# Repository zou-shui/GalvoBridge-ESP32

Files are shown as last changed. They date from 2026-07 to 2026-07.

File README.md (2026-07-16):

# GalvoBridge-ESP32：振镜双电源与数模转换一体化接口板

立创开源平台链接：[振镜双电源与数模转换一体化接口板 - 立创开源硬件平台](https://oshwhub.com/zoushui/project_hrrvwklm)

效果演示：[【开源】振镜驱动效果演示](https://www.bilibili.com/video/BV1rFKG6pEkv/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)

## 项目简介

**GalvoBridge-ESP32** 是一款专为模拟激光振镜系统设计的**一体化信号与电源适配接口板**。它集成了24V转±15V的**双电源转换模块** 与 **数字信号转模拟差分信号调理电路**，并集成了激光笔电源接口。

该项目旨在解决数字系统与模拟振镜系统之间的电压与信号鸿沟，实现一根 USB 线、一个24V电源即可轻松玩转振镜。

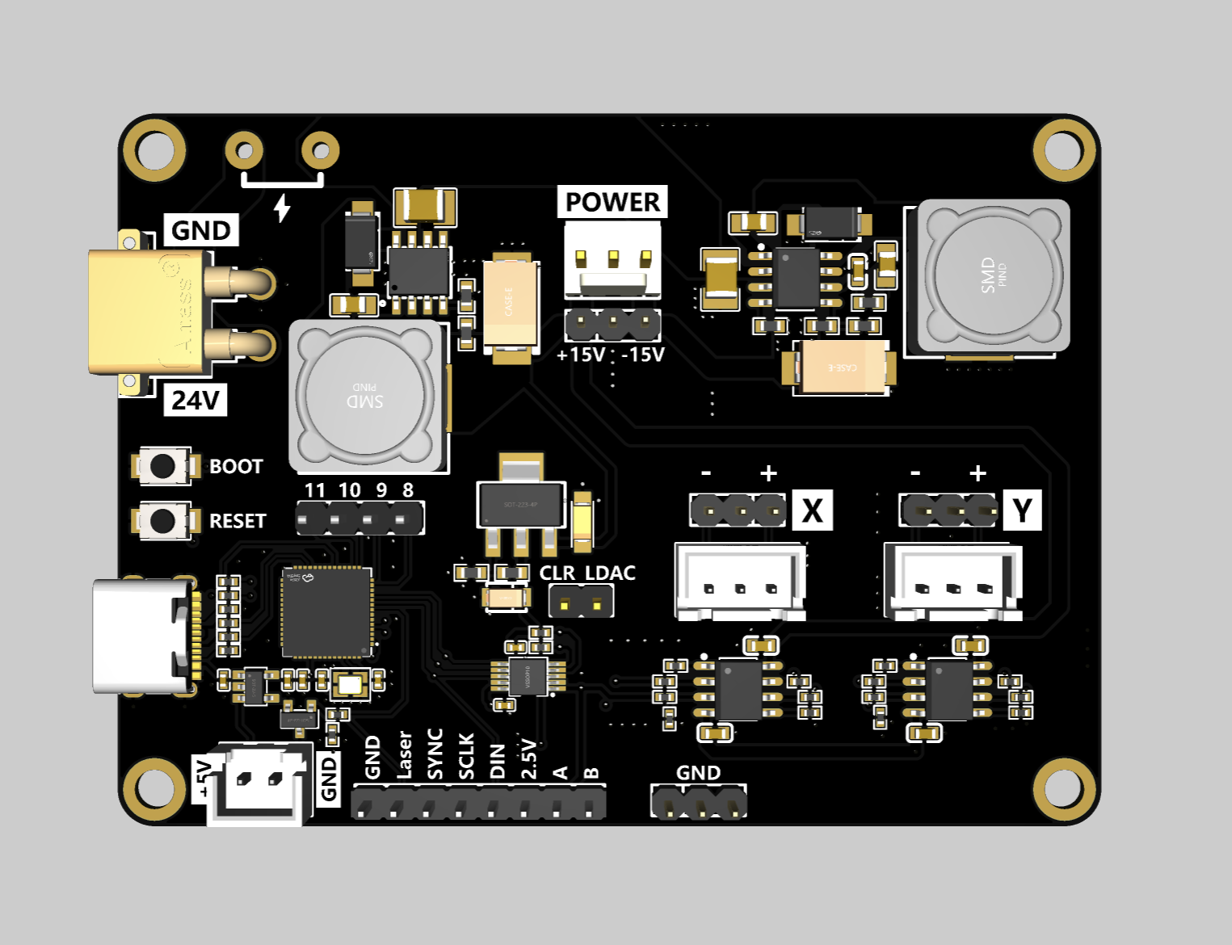
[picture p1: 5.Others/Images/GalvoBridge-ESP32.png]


## 为什么会有这个项目？

在进行激光打标、激光投影相关的 DIY 开发时，市售的振镜电机通常会成套附带一块原厂伺服驱动板（见下图）：

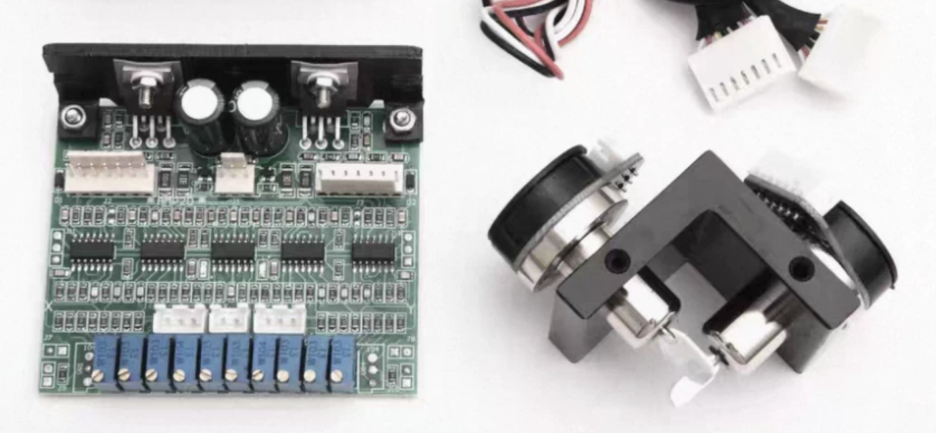
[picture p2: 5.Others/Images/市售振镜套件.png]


然而，在实际使用中，原厂驱动板存在两个“高门槛”：

1. **供电苛刻：** 振镜驱动板通常需要特殊的**±15V双电源**供电。在大多数整机系统中，标准电源都是单24V，额外配置一个体积庞大的双电源开关电源既增加成本又占地方。

2. **信号不匹配：** 振镜驱动板只接收**±5V的模拟差分信号**来控制振镜。单片机或DAC无法直接提供匹配的信号。

本项目解决了上述痛点。

## 实现原理

* **高负载双电源方案**：采用两颗高效率 DCDC 电源芯片，将整机常用的单路+24V电源分别转换为高电流能力的+15V和-15V双电源，直接为振镜伺服系统供电。

* **数模转换与信号调理**：核心主控采用 **ESP32-S3**，通过 USB 串口接收上位机数字指令并进行解析。控制高性能双通道 DAC 芯片输出高精度模拟信号，再经过运算放大器进行**电平平移（偏置）、幅度放大以及差分化处理**，最终输出±5V幅值的模拟差分信号。

## 详细参数

| 项目 | 参数 |
| --- | --- |
| 电源输入 | +24V（XT30接口）；+5V（Type-C接口） |
| 双电源输出 | ±15V（KF2510接口，3Pin，每路峰值 3A） |
| 差分信号输出 | XH2.54接口，幅值 -5V ~ +5V，最高 25k points/s（双通道同步输出） |
| 激光笔供电/控制 | XH2.54接口，5V，NMOS 驱动 |

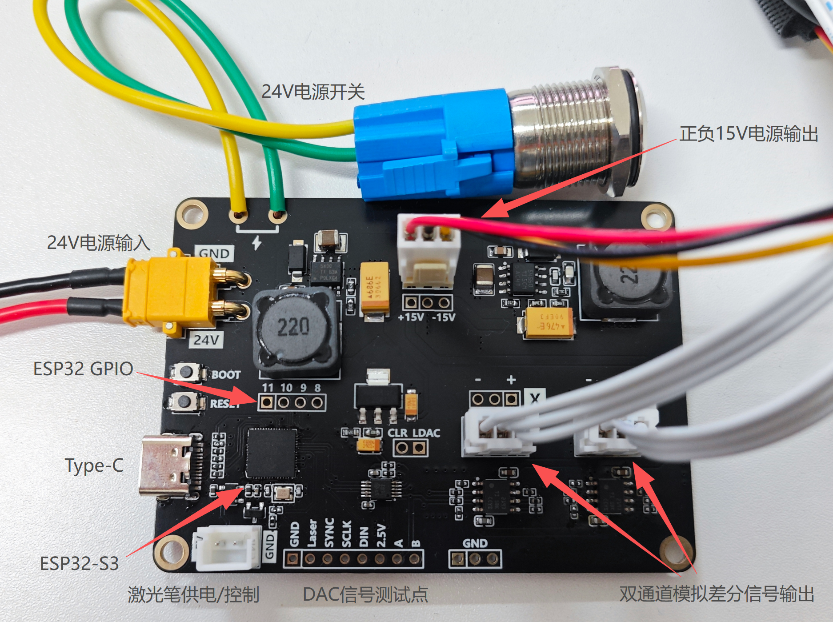
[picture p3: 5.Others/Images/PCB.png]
PCB实物图


全家福

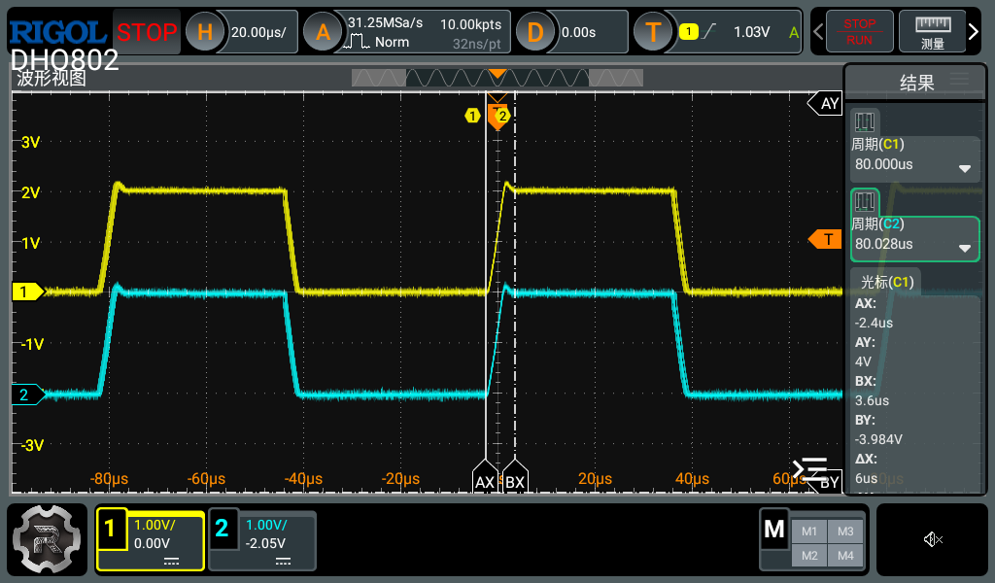
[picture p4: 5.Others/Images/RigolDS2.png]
输出波形测试


> 上图为在25k points/s的输出速率下，以2V为阶跃步长测试DAC输出，测得建立时间≤6us，抖动<2us，完全满足市售25k振镜的最高工作速率。

## Q&A：

Q: 为什么使用成本较高的ESP32-S3？

A: 因为ESP32-S3主频高，开发环境自带Free RTOS，完全满足25K points/s的打点速率。当然也可以不用ESP32：预留了DAC的SPI接口以及两个通道的输出信号的测试排针，用开发板连接排针一样可以驱动DAC。

Q: 为什么振镜不响应串口指令？

A: 检查两个通道是否按期望值输出、检查DAC通讯是否正常、检查DAC和运放电源是否正常、检查单片机是否正常工作。 另外，**24V和5V的上电顺序**也需要注意：请确保24V先于5V上电，或两者同时上电后再复位一次ESP32，否则DAC在上电时未就绪将导致初始化失败。

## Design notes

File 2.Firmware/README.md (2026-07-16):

# Firmware

本目录存放GalvoBridge-ESP32的固件及源码，硬件平台：ESP32-S3（Arduino 框架）。构建系统：PlatformIO。如要自行修改固件，请先安装PlatformIO。

由于PlatformIO官方尚未提供 ESP32-S3FH4R2 的板卡定义文件，
请手动将 `esp32-s3-fh4r2.json` 放入 PlatformIO 的 boards 目录：

Windows:
C:/Users/<用户名>/.platformio/platforms/espressif32/boards/

Linux / macOS:
~/.platformio/platforms/espressif32/boards/

之后即可正常打开工程。

## 如果想直接烧录固件

使用`5.Others/Tool`下的`flash_download_tool`工具烧录`2.Firmware/firmware`下的三个`bin`文件，具体配置截图可在`Tool`文件夹下找到。另外可参考官方的烧录步骤[Flash 下载工具用户指南 - ESP32 - — ESP 测试工具 latest 文档](https://docs.espressif.com/projects/esp-test-tools/zh_CN/latest/esp32/production_stage/tools/flash_download_tool.html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)

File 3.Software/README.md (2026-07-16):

# Software

本目录提供两个用于测试GalvoBridge-ESP32的python脚本。

## 1. send_circle.py (静态圆形生成器)

**功能**：在内存中预先生成一个由 $N$ 个点（默认 400 点）组成的标准圆轨迹，打包成一个数据包并单次发送。

## 2. send_mouse.py (实时鼠标追踪器)

**功能**：以 100Hz 的频率实时捕获 Windows 屏幕上的鼠标光标位置，并将其映射为 16 位坐标发送。

---

## 环境准备与安装

1. **确保 Python 环境已安装**（建议 Python 3.8 及以上版本）。

2. **安装依赖**：
   在脚本所在目录下打开终端，运行以下命令安装串口通信库：
   
   ```bash
   pip install -r requirements.txt
   ```

3. 运行
   
   ```bash
   python send_circle.py
   ```
   
   ```bash
   python send_mouse.py
   ```

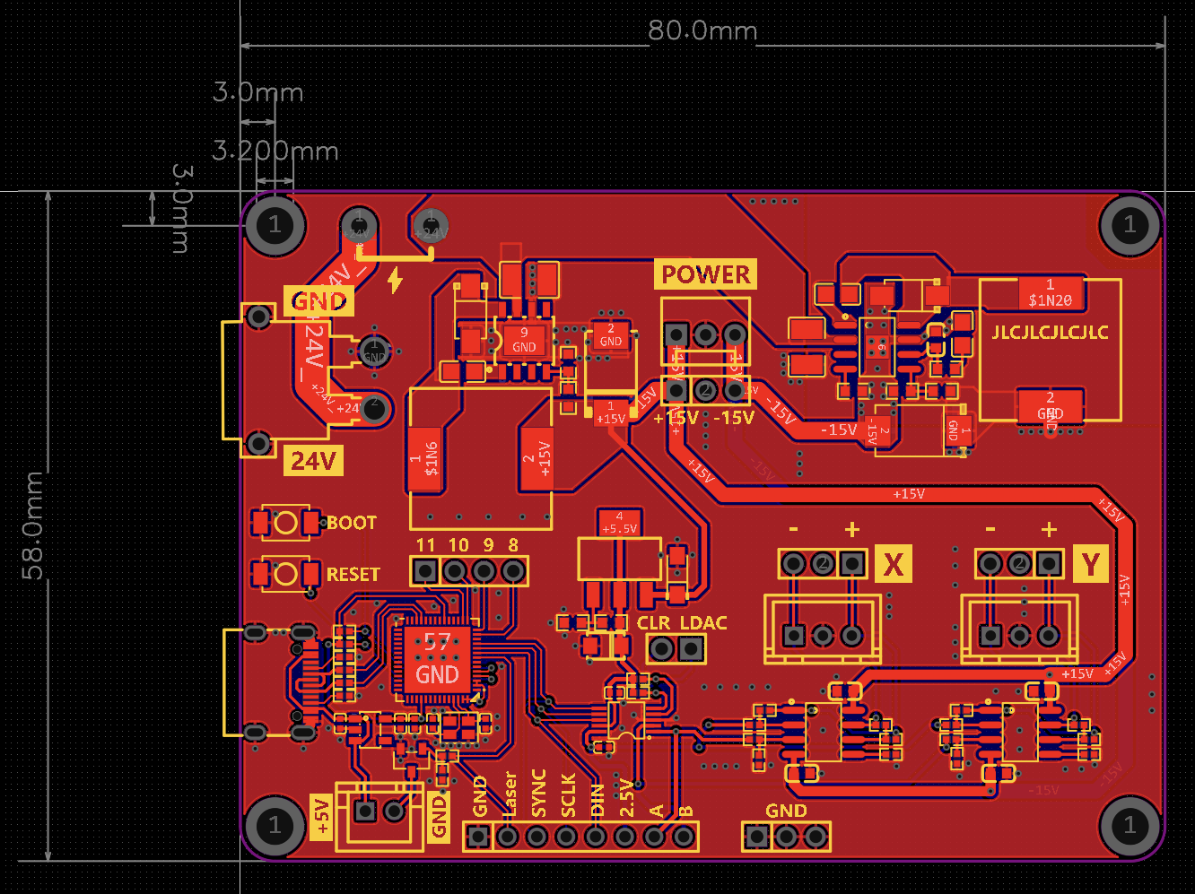
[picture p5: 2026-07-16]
1.Hardware/尺寸.png

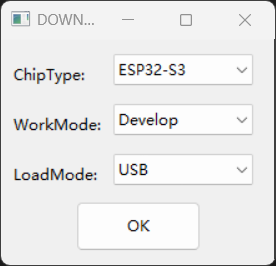
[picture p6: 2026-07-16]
5.Others/Tool/步骤1.png

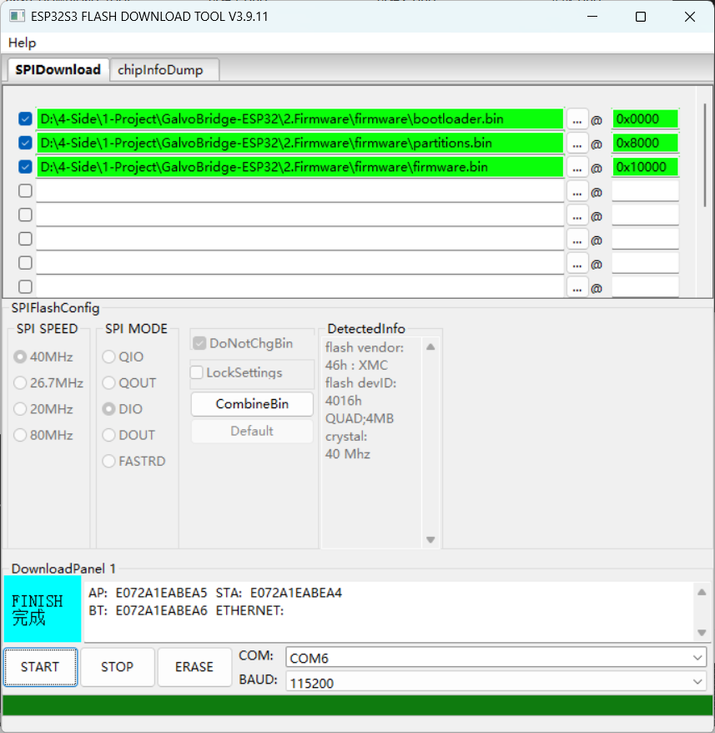
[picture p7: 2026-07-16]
5.Others/Tool/完成.png

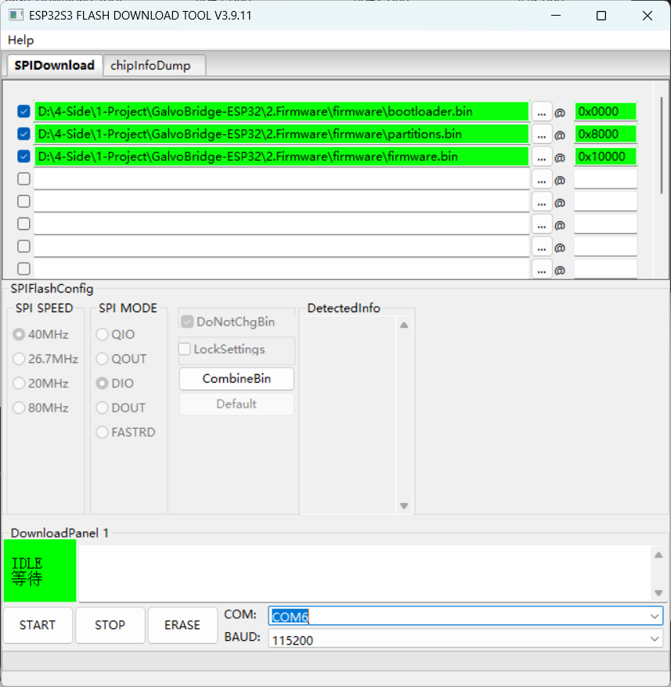
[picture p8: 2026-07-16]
5.Others/Tool/步骤2.png

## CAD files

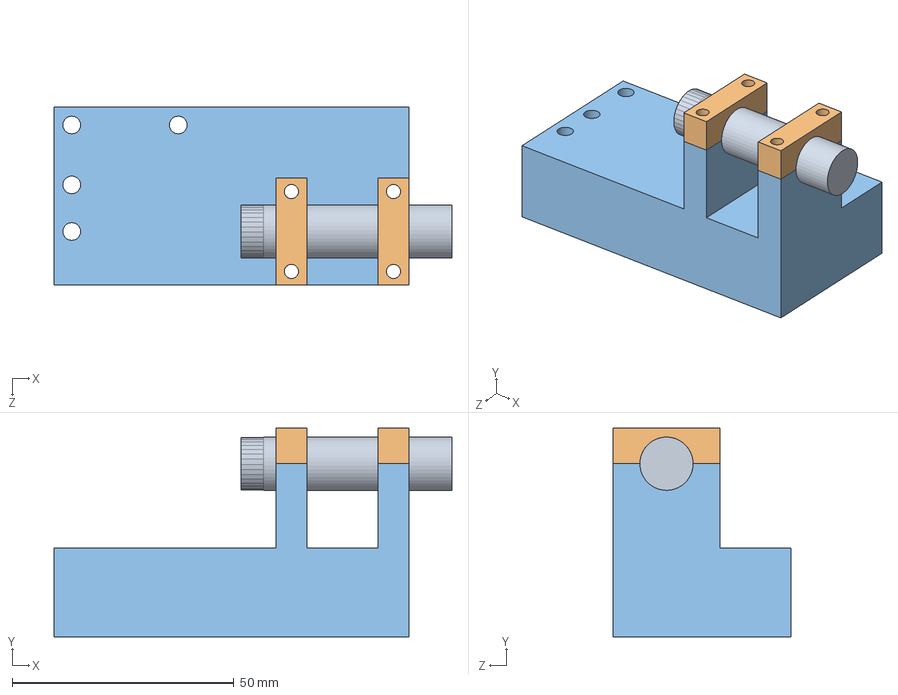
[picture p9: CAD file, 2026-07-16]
4.Model/装配体.SLDASM
89.7 x 47.0 x 40.0 mm
激光笔固定底座
激光笔固定盖 x 2
激光笔

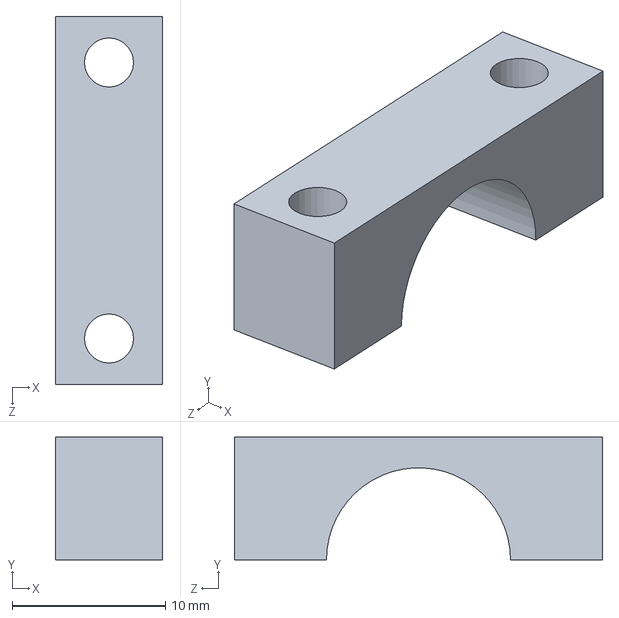
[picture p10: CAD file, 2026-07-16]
4.Model/激光笔固定盖.SLDPRT
7.00 x 8.00 x 24.0 mm

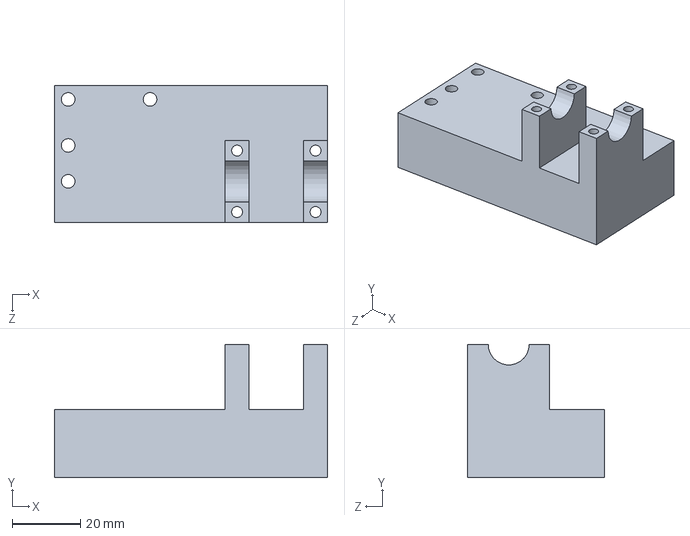
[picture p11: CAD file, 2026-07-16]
4.Model/激光笔固定底座.SLDPRT
80.0 x 39.0 x 40.0 mm

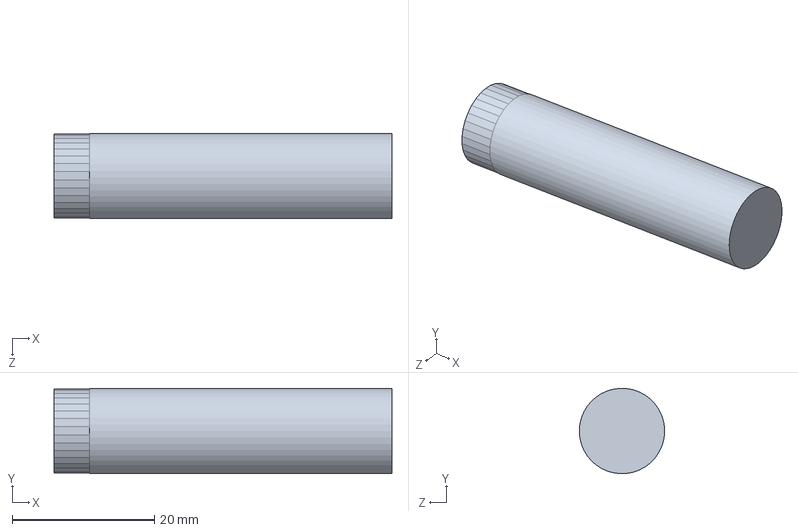
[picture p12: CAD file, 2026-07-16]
4.Model/激光笔.SLDPRT
47.5 x 12.0 x 12.0 mm

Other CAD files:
4.Model/激光笔固定底座.STL
4.Model/激光笔固定盖.STL

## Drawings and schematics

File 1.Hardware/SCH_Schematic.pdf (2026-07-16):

运放

# DAC

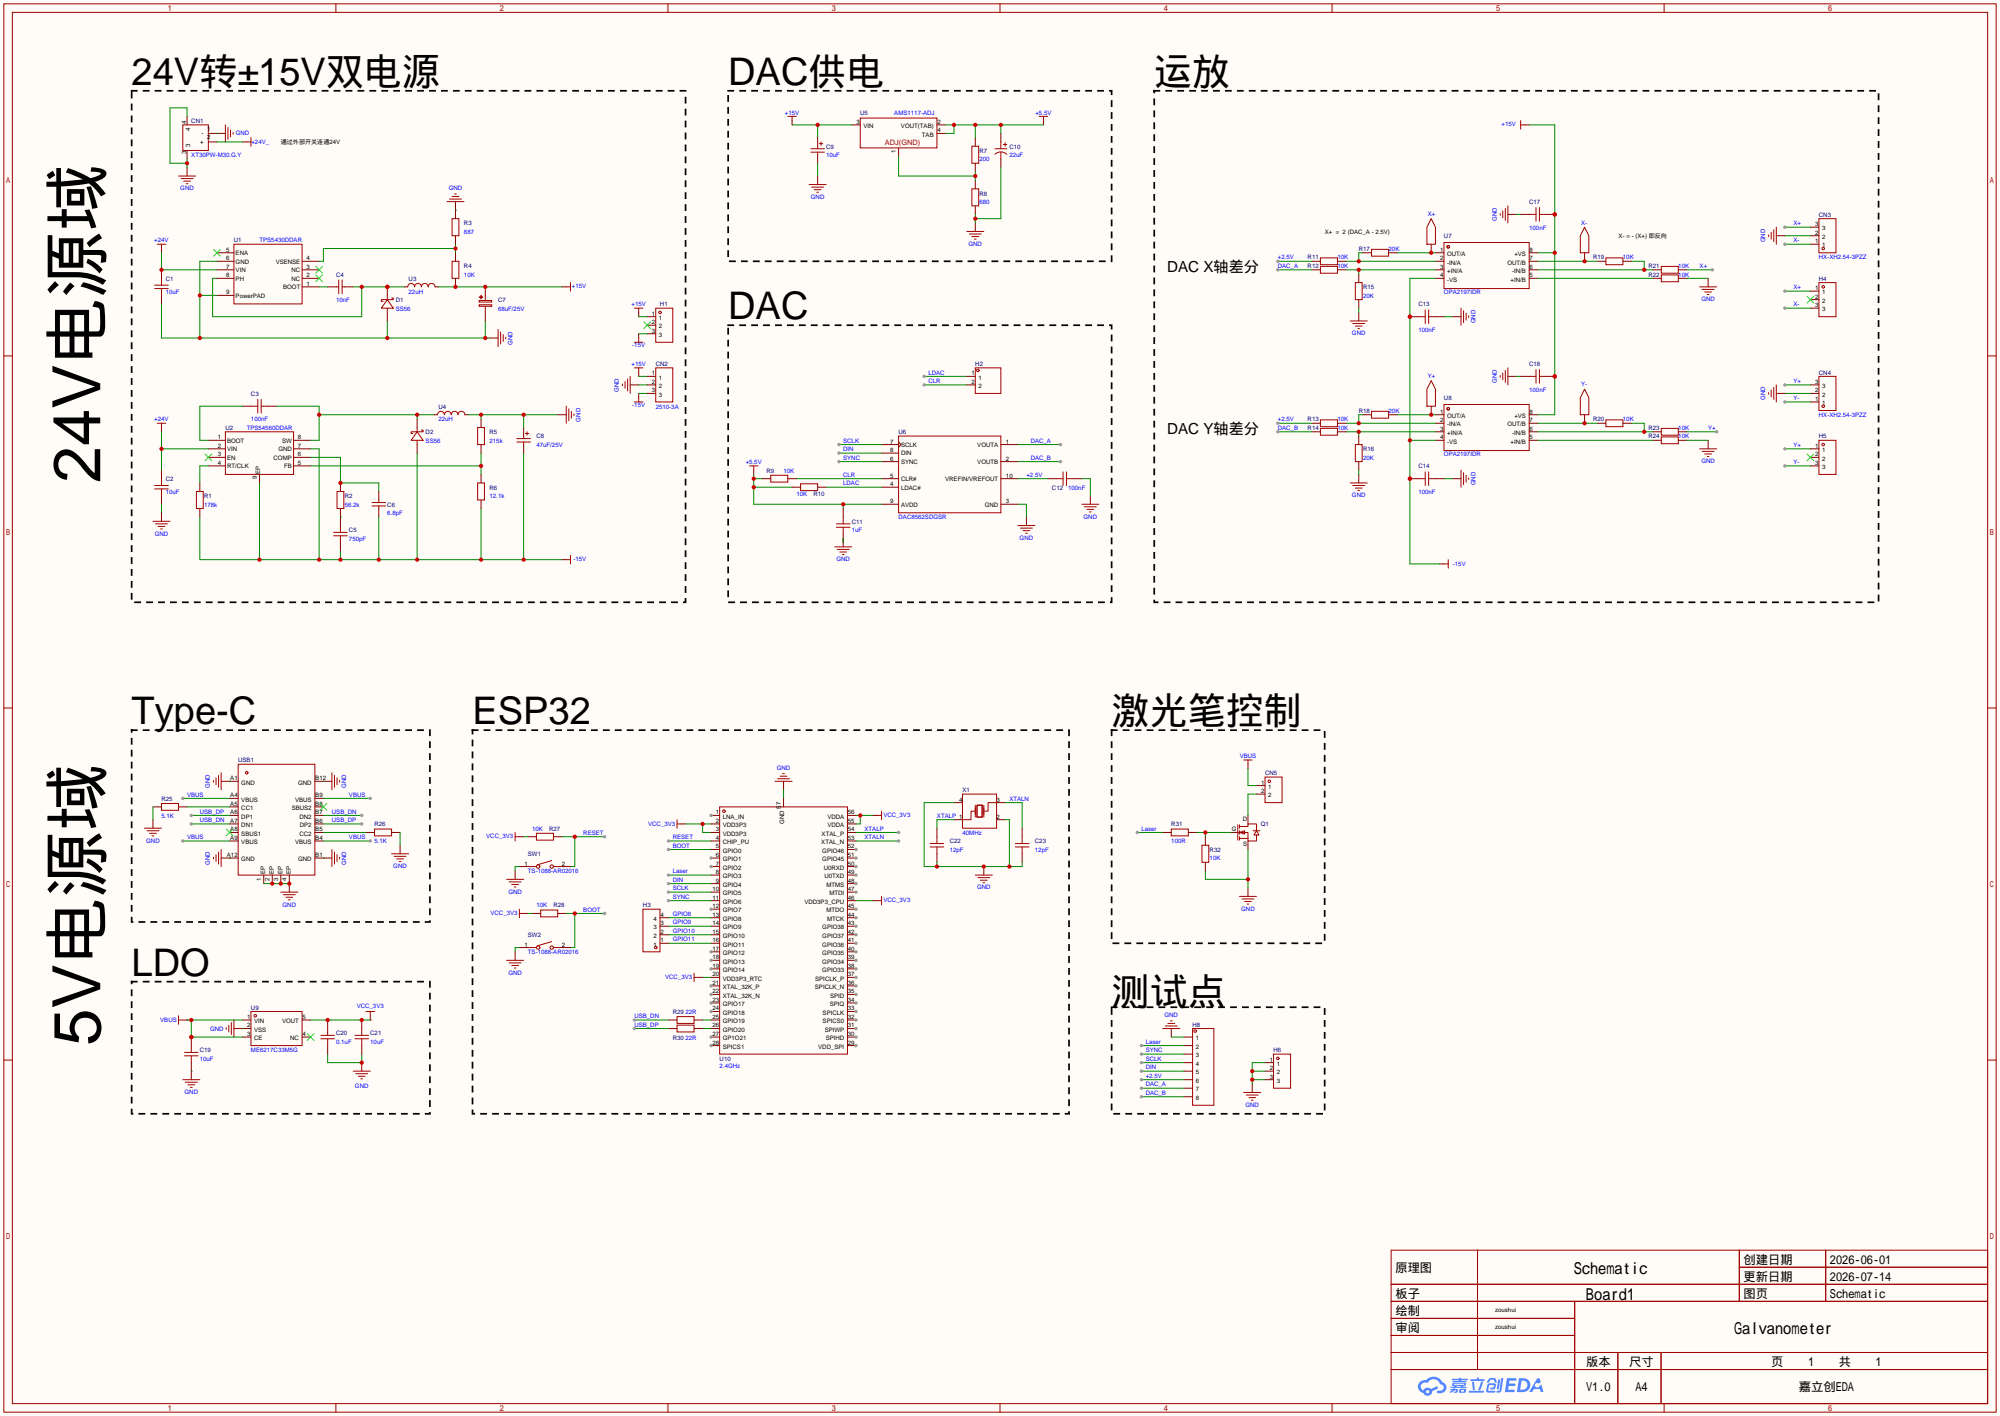
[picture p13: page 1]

原理图 | Schematic | 创建日期 | 2026-06-01

更新日期 | 2026-07-14

板子 | Board1 | 图页 | Schematic
绘制 | zoushui | Galvanometer
审阅 | zoushui

V1.0 | A4 | 嘉立创EDA

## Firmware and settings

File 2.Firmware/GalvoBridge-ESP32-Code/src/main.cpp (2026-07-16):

#include <Arduino.h>
#include "DAC8562.h"
#include "GalvoParser.h"
#include "LaserCtrl.h"

DAC8562 dac;
hw_timer_t *timer = NULL;

void IRAM_ATTR onTimer()
{
    static uint32_t current_point_idx = 0; // 当前播放到哪一个点

    point_t *current_frame = NULL;
    uint32_t total_points = 0;

    // 从解析器模块直接抓取当前的“播放缓冲区”指针和点数
    galvoParser_getRenderFrame(&current_frame, &total_points);

    // 如果没有数据，或者数据点数为0，维持输出中心点
    if (total_points == 0 || current_frame == NULL)
    {
        dac.sync_outputs(32768, 32768);
        current_point_idx = 0;
        return;
    }

    // 安全边界检查：如果串口突然切换了帧，并且新帧点数变少了，防止索引越界
    if (current_point_idx >= total_points)
    {
        current_point_idx = 0;
    }

    // 吐出当前点的 X, Y 坐标给 DAC 芯片
    dac.sync_outputs(current_frame[current_point_idx].x, current_frame[current_point_idx].y);

    // 递增索引，如果到了画面末尾，自动重头循环（振镜需要高频不断地重绘画面）
    current_point_idx++;
    if (current_point_idx >= total_points)
    {
        current_point_idx = 0;
    }
}

void setup()
{
    Serial.begin(921600);

    dac.begin();
    dac.sync_outputs(32768, 32768);

    delay(1000);

    // 1. 初始化解析器：这会在后台建立一个独立运行的串口扫描任务
    galvoParser_init();

    // 2. 启动硬件定时器
    timer = timerBegin(0, 80, true);
    timerAttachInterrupt(timer, &onTimer, true);
    timerAlarmWrite(timer, 40, true);
    timerAlarmEnable(timer);

    Serial.println("Ready @ 921600 bps");

    laserCtrl_init();
}

void loop()
{
}

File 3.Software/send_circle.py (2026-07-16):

"""
向串口发送标准圆的坐标点序列。

数据格式 (大端序):
  FF FF | N(2B) | X1 Y1(4B) | ... | Xn Yn(4B)

每个坐标轴 16 位无符号，原点 0x7FFF。
"""

import math
import struct
import time
import serial

# ====== 可配置参数 ======
COM_PORT = "COM9"
BAUDRATE = 921600
POINT_COUNT = 400          # 点数量
ORIGIN = 0x7FFF              # 原点 (32767)
RADIUS = 0x6000              # 圆半径
# =======================


def generate_circle_points(n: int, cx: int, cy: int, r: float) -> list[tuple[int, int]]:
    """生成标准圆上的 n 个点，均匀分布。"""
    points = []
    for i in range(n):
        angle = 2.0 * math.pi * i / n
        x = int(cx + r * math.cos(angle))
        y = int(cy + r * math.sin(angle))
        if x < 0:
            x = 0
        elif x > 0xFFFF:
            x = 0xFFFF
        if y < 0:
            y = 0
        elif y > 0xFFFF:
            y = 0xFFFF
        points.append((x, y))
    return points


def build_packet(points: list[tuple[int, int]]) -> bytes:
    """按照协议格式打包数据。"""
    n = len(points)
    # 大端序打包: header(2B) + N(2B) + points(4B each)
    data = struct.pack(">HH", 0xFFFF, n)            # header + count
    for x, y in points:
        data += struct.pack(">HH", x, y)            # x + y
    return data


def main():
    print(f"生成 {POINT_COUNT} 个圆坐标点 (原点=0x{ORIGIN:04X}, 半径=0x{RADIUS:04X})...")
    points = generate_circle_points(POINT_COUNT, ORIGIN, ORIGIN, RADIUS)
    print(f"坐标生成完成，首点: (0x{points[0][0]:04X}, 0x{points[0][1]:04X})")

    print("打包数据帧...")
    packet = build_packet(points)
    print(f"数据帧大小: {len(packet)} 字节 (预期: {2+2+POINT_COUNT*4})")

    print(f"打开串口 {COM_PORT} @ {BAUDRATE} bps...")
    ser = serial.Serial(COM_PORT, BAUDRATE, timeout=1)

    print("发送数据...")
    start = time.time()
    ser.write(packet)
    ser.flush()                     # 等待硬件 FIFO 排空
    elapsed = time.time() - start

    print(f"发送完成，耗时 {elapsed:.2f}s, 速率 {len(packet)*8/elapsed/1000:.1f} kbps")
    ser.close()
    print("串口已关闭。")


if __name__ == "__main__":
    main()

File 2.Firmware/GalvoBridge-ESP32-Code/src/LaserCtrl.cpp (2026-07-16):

#include "LaserCtrl.h"
#include <Arduino.h>

#define LASER_CTRL_PIN 3   // GPIO3 控制激光笔
#define LASER_TOGGLE_PIN 0 // GPIO0 下降沿触发使能切换

// 内部状态
static volatile bool laser_enabled = true; // 使能标志

/**
 * GPIO0 下降沿中断服务函数
 * 每次触发时翻转使能状态；若变为未使能，立即关闭激光
 */
void IRAM_ATTR laser_toggle_isr()
{
    laser_enabled = !laser_enabled;
    if (laser_enabled)
    {
        digitalWrite(LASER_CTRL_PIN, HIGH); // 使能后默认打开
    }
    else
    {
        digitalWrite(LASER_CTRL_PIN, LOW); // 关闭激光
    }
}

void laserCtrl_init()
{
    pinMode(LASER_CTRL_PIN, OUTPUT);
    digitalWrite(LASER_CTRL_PIN, HIGH);

    // 配置触发引脚，内部上拉，下降沿中断
    pinMode(LASER_TOGGLE_PIN, INPUT_PULLUP);
    attachInterrupt(digitalPinToInterrupt(LASER_TOGGLE_PIN), laser_toggle_isr, FALLING);
}

void laser_ON()
{
    if (laser_enabled)
    {
        digitalWrite(LASER_CTRL_PIN, HIGH);
    }
}

void laser_OFF()
{
    digitalWrite(LASER_CTRL_PIN, LOW);
}

bool laserCtrl_isEnabled()
{
    return laser_enabled;
}
